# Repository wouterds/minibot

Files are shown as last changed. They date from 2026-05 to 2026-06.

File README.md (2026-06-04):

# minibot

A small invertible 4WD ESP32 robot driven by a PS3 controller over Bluetooth.




## Overview

- **ESP32 (WeMos LOLIN32 Lite)** — WiFi + Bluetooth Classic
- **PS3 DualShock 3 controller** as the wireless remote (BT Classic + HID)
- **4× N20 6 V / 400 RPM** gear motors, paired left/right through a single **DRV8833** dual H-bridge
- **MPU-6050 IMU** for orientation detection — auto-flips drive direction when the bot is upside-down
- **TP4056 USB-C charge + DW01A protection board** — handles charging, overcharge, overdischarge and short-circuit protection
- **1S LiPo 3.7 V / 1000 mAh (603048)**, ~1 hour of cruising
- **3D-printed PETG translucent chassis** — fully enclosed (2.5 mm walls all around), invertible, ~130 × 130 × 18 mm

## System

```mermaid
flowchart LR
    PS3([PS3 Controller]) -->|HID / Bluetooth Classic| ESP[ESP32<br/>LOLIN32 Lite]
    IMU[MPU-6050 IMU] -->|I²C<br/>orientation| ESP
    ESP -->|2 PWM pins / side<br/>3.3 V logic| DRV[DRV8833]
    DRV -->|VM rail| MOT[4× N20 motors<br/>2 paired per side]
    BAT[(1S LiPo<br/>3.7 V / 1000 mAh)] -->|B+ / B-| TP[TP4056<br/>charge + protect]
    TP -->|OUT+ protected VBAT| ESP
    TP -.->|OUT+ to VM| DRV
```

## Wiring

| ESP32 pin | Destination | Purpose |
|---|---|---|
| `3V3` | DRV8833 `SLP`, MPU-6050 `VCC` | Wake the driver, power the IMU |
| `GND` | All `GND` | Common ground |
| `+` pad next to JST | DRV8833 `VM` (from TP4056 `OUT+`) | Motor supply, protected battery (3–4.2 V). Solder to the **pad next to the white JST connector**, not a side-header pin. |
| `GPIO 19` | Status LED | Connection indicator |
| `GPIO 21` | MPU-6050 `SDA` | I²C data (IMU) |
| `GPIO 22` | MPU-6050 `SCL` | I²C clock (IMU) |
| `GPIO 13` | DRV8833 `AIN1` | Left side PWM bit 1 |
| `GPIO 14` | DRV8833 `AIN2` | Left side PWM bit 2 |
| `GPIO 26` | DRV8833 `BIN1` | Right side PWM bit 1 |
| `GPIO 27` | DRV8833 `BIN2` | Right side PWM bit 2 |

Each motor uses **2 PWM-capable GPIOs**: drive one HIGH/PWM and hold the other LOW to spin one direction, swap to reverse. The two motors on each side are wired in parallel to a single driver channel — `AOUT1` / `AOUT2` drive both left motors, `BOUT1` / `BOUT2` both right motors. See [`research.md`](research.md) for the design rationale.

## Power

```mermaid
flowchart LR
    USBC([USB-C 5 V]) -->|Vbus| TP[TP4056<br/>charge IC]
    TP -->|charge| BAT[(1S LiPo<br/>3.0–4.2 V)]
    BAT --> DW[DW01A<br/>protection IC]
    DW -->|OUT+ protected| LDO[LOLIN32<br/>3.3 V LDO]
    DW -->|OUT+ raw| VM[DRV8833 VM]
    LDO -->|3.3 V| LOGIC[ESP32 core<br/>+ DRV8833 SLP, IMU VCC]
    VM -->|3–4 A peak| MOT[4× N20 motors]
```

USB-C plugs into the **TP4056** board: it charges the battery (constant-current → constant-voltage) and the paired **DW01A** protects against overcharge, overdischarge, overcurrent, and short-circuit. The **OUT+ / OUT-** terminals are the protected battery output that feeds both the LOLIN32's 3.3 V LDO and the DRV8833's VM rail. The LOLIN32's onboard TP4054 + JST connector is left unused — battery only ever connects to the TP4056's `B+ / B-`.

## Chassis

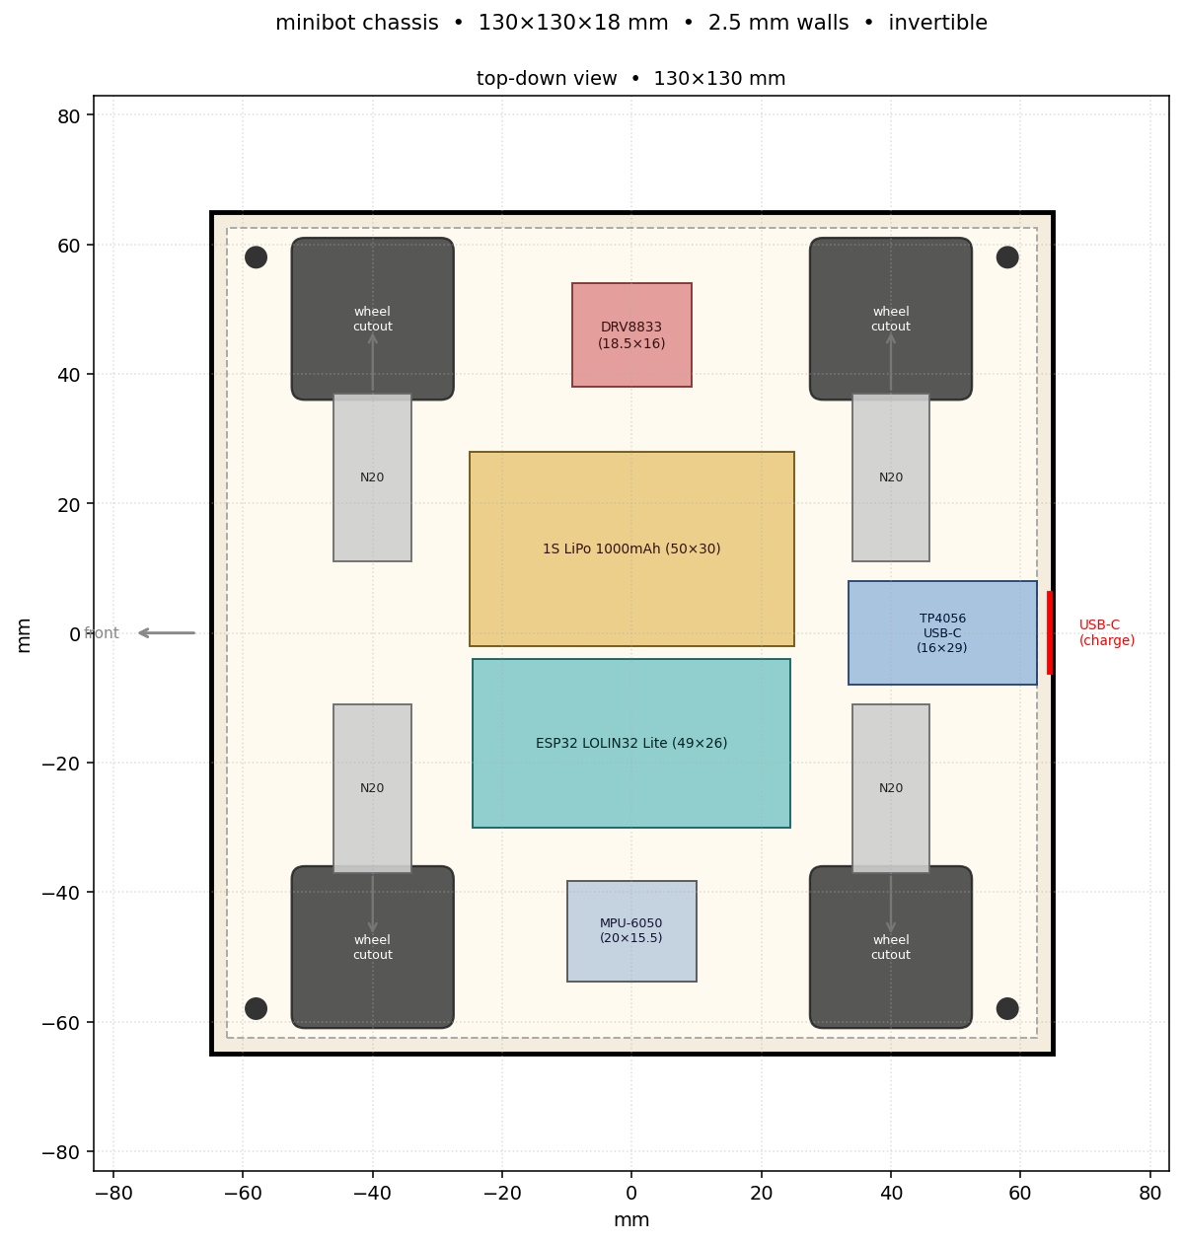
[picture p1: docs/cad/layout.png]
Top-down chassis layout


Two identical tray-shaped plates (3 mm floor + 6 mm half-walls) join open-face-to-open-face into a closed box. Four motors mount in half-cylinder pockets in each plate, shafts pointing outward toward the side walls. Wheels sit on the shafts close to but inside the walls, and protrude only through cutouts in the top and bottom plates. Nothing is exposed laterally.

The parametric source is at [`docs/cad/chassis.scad`](docs/cad/chassis.scad). Render to STL with OpenSCAD:

```sh
openscad --export-format=stl -o plate.stl docs/cad/chassis.scad
```

Print the same shape twice — the chassis is invertible.

### Print settings

| Setting | Value |
|---|---|
| Material | PETG translucent |
| Plate thickness | 3 mm |
| Layer height | 0.2 mm |
| Infill | 25–30 % gyroid |
| Perimeters | 3–4 walls |
| Orientation | Plates flat on the bed |
| Mounting | M2.5 heat-set inserts in the long-edge bosses |

## Parts

Quick summary — see [`docs/parts.md`](docs/parts.md) for the full list with vendors.

| Component | Qty | ~Cost |
|---|---|---:|
| ESP32 LOLIN32 Lite | 1 | €5–8 |
| DRV8833 breakout | 1 | €1.50 |
| N20 6 V 400 RPM motor, 20 mm shaft | 4 | €10 |
| JS2622 wheel (⌀25 × 23 mm) | 4 | €7.20 |
| MPU-6050 IMU module | 1 | €1.50 |
| TP4056 USB-C charge + DW01A protection board | 1 | €1–2 |
| 1S LiPo 1000 mAh (603048) | 1 | €6 |
| PETG translucent (chassis) | ~50 g | €1–2 |
| M2.5 hardware, wire, heat-shrink | — | €5–8 |
| PS3 controller (reuse) | 1 | €0–20 |
| **Total (minimum viable build)** | | **~€33–44** |

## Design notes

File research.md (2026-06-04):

# Research notes

Running log of what we learned while building minibot. Updated as we go.

## Hardware

### ESP32 dev board

- **Chip**: ESP32-D0WDQ6 rev v1.0 — original ESP32, dual-core Xtensa LX6 @ 240 MHz, WiFi + BT/BLE
- **USB-to-serial**: CH340 (`1a86:7523`) → `/dev/cu.usbserial-110`
- **Crystal**: 41.01 MHz reported (a bit off the 40 MHz spec — common quirk on CH340 clones)
- **Base MAC**: `24:6F:28:B1:F8:B4` (WiFi STA)
- **Bluetooth MAC**: `24:6F:28:B1:F8:B6` (= base + 2, per ESP32's MAC derivation rule)
- **Board**: WeMos LOLIN32 Lite (or clone) — confirmed by visible silkscreen + features
- **Footprint**: ~52 × 25 × 5 mm (no headers soldered, direct-wire build)
- **Onboard**:
  - JST PH2.0 connector for 1S LiPo (top edge) — **unused** in current build (battery routes through TP4056 instead)
  - TP4054 LiPo charge IC — **bypassed**; charging handled by external TP4056 + DW01A board
  - 3.3V LDO regulator
  - CH340C USB-serial
  - Micro-USB connector — used for programming only
  - RST button
  - PCB antenna (no external connector)
- **Power pins exposed**:
  - `+` (next to JST) — raw battery voltage (3.0–4.2V), perfect for feeding DRV8833 `VM`
  - `3V` — regulated 3.3V, for DRV8833 `SLP` (sleep/enable) and IMU `VCC`
  - `GND` — common ground
- **Pin labels visible**: `UP` (= GPIO 36 / SENSOR_VP), `UN` (= GPIO 39 / SENSOR_VN), `EN`, plus GPIOs 0, 2, 4, 5, 12–19, 22, 23, 25–27, 32–35

### PS3 controller

- **VID/PID**: `054c:0268` (Sony DualShock 3 / SIXAXIS)
- **Manufacturer string**: `SHANWAN` — it's a clone, not a genuine Sony. Most clones work with standard pairing flow.

### Motors

- **Type**: N20 micro metal gear motors, **6V 400 RPM, 20mm shaft** (4×)
- **Voltage choice**: 6V over 3V because the 3.7V LiPo (4.2V full) overvolts a 3V motor by 23–40%, shortening lifespan and risking thermal failure under stall. Undervolting a 6V motor is harmless — it just runs slower, with more headroom on heat and stall current.
- **Shaft length**: 20mm to match deep-hub wheels (JS2622, measured ⌀25 × 23 mm). Standard ~9mm shafts would slip in deep hubs.
- **RPM choice**: 400 RPM was the practical pick from what's actually in stock — ideal would have been 600 RPM for a snappier "speedy" feel, but 400 RPM is still a usable balance of speed and torque. At 3.7V loaded with the 25mm JS2622 wheels: ~1.0 km/h cruise, ~1.1 km/h peak. Future upgrade path: 2S LiPo (7.4V) would push it to ~1.8 km/h.
- **Visible gear stages identical across all 4** → same gear ratio → same output RPM at same voltage.
- **Current draw**: ~200 mA cruise, 500–700 mA stall per motor. Paired (2× per side) → 1–1.4 A stall per side — within DRV8833's 1.5 A continuous / 2 A peak window.
- **Encoders**: none — open-loop control only (we command, we don't sense).

### Motor driver: DRV8833

Picked over the alternatives for our 4× N20 setup:

| Driver | Price / unit | Continuous | Peak | Notes |
|---|---|---|---|---|
| **DRV8833** ✅ | ~€1.50 | 1.5 A / ch | 2 A (3 A paralleled) | MOSFET, compact (18.5 × 16 mm), no separate VCC needed, fewer GPIOs |
| TB6612FNG | ~€1.50 | 1.2 A / ch | 3 A | MOSFET, clean API (separate PWM pin), but 22 × 22 mm and needs 6 GPIOs instead of 4 |
| L298N | ~€2 | 2 A / ch | — | BJT, ~2 V drop → wastes battery as heat |
| L9110S / MX1508 | ~€1 | 800 mA / ch | — | Marginal for stalled N20s |

Plan: **1× DRV8833 breakout** for the basic 4-motor tank drive — see the [paired-motors topology](#paired-motors-per-side) below: each pair of motors on one side is wired in parallel and treated as one logical motor, so we only need 2 driver channels total.

### DRV8833 control logic

Each motor is driven by **two PWM-capable GPIOs** (no separate PWM-vs-direction pins). Drive one HIGH/PWM and hold the other LOW to spin one direction; swap to reverse:

| `xIN1` | `xIN2` | Result |
|---|---|---|
| `LOW` | `LOW` | Coast (high-impedance, motor freewheels) |
| `PWM` | `LOW` | Forward at PWM duty |
| `LOW` | `PWM` | Reverse at PWM duty |
| `HIGH` | `HIGH` | Brake (short across motor) |

This costs 4 GPIOs total (vs 6 for the TB6612FNG alternative) but requires both pins on each motor channel to be PWM-capable. ESP32 LEDC has 16 channels so that's no constraint.

## Software stack

### Why PlatformIO + Arduino framework

Considered Moddable SDK (TypeScript on ESP) first — beautiful idea but installing the SDK + ESP32 toolchain + ESP-IDF was a multi-GB, multi-hour setup. Dropped TS-as-hard-requirement in favour of:

- **PlatformIO IDE** (VSCode extension) — handles toolchain, library mgr, debugger, monitor, all from one extension
- **Arduino framework** on `espressif32` platform — friendlier than raw ESP-IDF, huge library ecosystem

One click in the PlatformIO status bar = build, upload, monitor. No env vars, no shell config.

### Key library

- `jvpernis/esp32-ps3` (pulled via `lib_deps` git URL) — handles PS3 BT Classic + HID + button/stick event callbacks

## PS3 controller pairing

PS3 pairing is **not** standard Bluetooth pairing. The controller stores **one** host MAC internally and will only connect to that address. There's no discovery, no PIN, no negotiation — the controller hunts for that exact MAC.

To pair:

1. Plug controller into a Mac/Linux host via USB.
2. Write the desired host MAC into the controller's memory via HID feature report `0xF5`.
3. Unplug USB → press PS button → controller auto-connects to that host over Bluetooth.

We do step 2 with `scripts/pair-ps3.py` (uses `hidapi` cython package; runs via `uv` with PEP 723 inline deps).

### Why not just `pip install hid`?

We tried the ctypes-based `hid` package first. On macOS, brew installs `libhidapi.dylib` to `/opt/homebrew/lib` which isn't a default dyld search path, and SIP strips `DYLD_FALLBACK_LIBRARY_PATH` when env-invoking system binaries — so the ctypes loader can never find the library.

The cython-based `hidapi` package builds a self-contained extension during install and bypasses the issue.

## ESP32 GPIO constraints

### Input-only pins (cannot drive outputs / LEDs / motor signals)

- **GPIO 34, 35, 36, 39** — no internal output drivers, no pull-ups/downs. ADC/sensor only.

### Strapping pins (avoid for outputs that need defined boot levels, or be careful)

- **GPIO 0** — boot mode select. Avoid for outputs.
- **GPIO 2** — boot mode. OK if not held HIGH at boot.
- **GPIO 12** — flash voltage select. Must be LOW at boot or chip enters wrong mode → won't boot.
- **GPIO 15** — debug print on boot. Must be HIGH or you lose early boot serial.
- **GPIO 5** — boot mode select. Generally fine as output, just floats high briefly at boot.

### Reserved

- **GPIO 6–11** — wired to internal SPI flash. Touching them = brick.
- **GPIO 1, 3** — UART0 used by USB-serial.

### Currently used

- `19` — status LED (solid when PS3 connected, blinks while waiting)
- `17, 25, 32, 33` — face-button LEDs (will be reallocated when motors arrive)

## Motor control

### Why a driver is mandatory

| | ESP32 GPIO | N20 motor |
|---|---|---|
| Voltage | 3.3 V | 3–6 V |
| Current | 12 mA max | 200 mA – 1 A |
| Direction | one-way | needs polarity swap to reverse |
| Back-EMF | fries logic | spikes voltage on every PWM cycle |

GPIO straight to motor = dead ESP32 in milliseconds.

### H-bridge truth table (DRV8833)

| IN1 | IN2 | Effect |
|---|---|---|
| HIGH | LOW | Forward |
| LOW | HIGH | Reverse |
| LOW | LOW | Coast (free spin) |
| HIGH | HIGH | Brake (short across motor) |

`PWMx` rides on top → speed magnitude.

### Stick → driver mental model

PS3 stick gives signed `-128..+127`. The driver only understands:

- **Unsigned PWM 0–255** (magnitude / how hard)
- **Two direction pins** (which way)

Code splits the signed stick value into `abs()` → PWM and `sign()` → IN1/IN2 levels. The H-bridge handles the polarity flip across the motor terminals so we never need "negative PWM".

### Open-loop vs closed-loop

Our bare N20s have **no encoders**, so we run **open-loop** — we command a direction + speed and trust the motor obeys. For:

- Precise distance ("drive 30 cm")
- Speed regulation under load
- Detecting stall against a wall

…we'd need N20s with **magnetic hall encoders** (~$3–5 extra per motor, quadrature output). Not in scope for v1.

## Power topology

```
USB-C ── TP4056 ── B+/B- ── Battery
              └── OUT+/OUT- ──┬── LOLIN32 + pin (VBAT → onboard 3.3V LDO)
                              └── DRV8833 VM (motor supply)

GND ── common across battery −, TP4056 OUT−, LOLIN32 GND, DRV8833 GND
```

The **TP4056 USB-C board** (with onboard DW01A protection IC) replaces the LOLIN32's built-in charging path:

- **B+ / B-**: battery terminals (TP4056 charges the cell here)
- **OUT+ / OUT-**: protected battery output. Cuts off automatically on overcharge (>4.25 V), overdischarge (<2.4 V), overcurrent or short-circuit.
- USB-C provides 5 V to charge — also passes through to the load while charging, so the bot can be driven from USB.

Why add the TP4056 if the LOLIN32 already has a TP4054 charge IC?

| Feature | LOLIN32 onboard | TP4056 board |
|---|---|---|
| Charge current control | ✅ | ✅ |
| Overcharge protection | ❌ (TP4054 stops at 4.2 V but no protection cutoff) | ✅ DW01A cuts at 4.25 V |
| Overdischarge protection | ❌ | ✅ DW01A cuts at 2.4 V |
| Short-circuit protection | ❌ | ✅ |
| USB connector | micro-USB | USB-C |

For a bot that gets thrown around (and where you really don't want a LiPo to over-discharge), TP4056 is worth the €1.50.

- **VM**: motor power, 3–13.5 V (from TP4056 OUT+, which is battery voltage)
- **VCC**: logic power, 3.3 V (from LOLIN32's onboard LDO, fed from `+` pin)
- **SLP** (sleep/enable on DRV8833): tie to 3.3 V to keep the driver awake (or wire to a GPIO for software sleep)
- **Decoupling**: a 100–470 µF cap across VM/GND helps absorb stall-current dips.

⚠️ Never pull motor current through ESP32's `VIN` or `3V3` pin — onboard LDO maxes out around 800 mA and the input diode is tiny. Motors get their power *directly* from the battery via the driver's `VM`.

⚠️ Don't plug the battery into both the LOLIN32's JST AND the TP4056 B+ at the same time — pick one path. We use TP4056 only.

## Paired motors per side

To save a driver and GPIO budget, **the two motors on each side are wired in parallel** and treated as a single logical motor:

```
Left Front  motor + ─┐
Left Rear   motor + ─┴───── Driver AO1
Left Front  motor − ─┐
Left Rear   motor − ─┴───── Driver AO2
```

(Same for the right side via BO1/BO2.)

Implications:

- **1 driver, not 2** — both sides fit on a single DRV8833 (one channel per side)
- **6 GPIOs instead of 12** for motor control
- **Current doubles per channel** — 2× N20 in parallel pull ~400 mA cruise, ~1.5–2 A at simultaneous stall. Within the DRV8833's 1.5 A continuous / 2 A peak window, but tight enough to want decent decoupling and a battery that can deliver it.
- **Both motors on a side must be matched** (same gear ratio + winding) so they spin at the same RPM under the same drive signal. Our 4× N20s look identical externally + share the same visible gear stages, so this should hold.
- **Wire polarity matters** — if a paired motor spins the "wrong way" relative to its partner, just flip its leads at the driver output. Don't try to fix it in software.

## Wiring plan (1× DRV8833, 4 motors paired, tank drive)

| Side | IN1 (PWM) | IN2 (PWM) | Driver / output | Motors |
|---|---|---|---|---|
| Left  | GPIO 13 | GPIO 14 | A channel (AOUT1 + AOUT2) | Left Front + Left Rear in parallel |
| Right | GPIO 26 | GPIO 27 | B channel (BOUT1 + BOUT2) | Right Front + Right Rear in parallel |

`SLP` → ESP32 `3V3`. `VM` → TP4056 `OUT+` (battery, 3–4.2 V). All `GND` rails common (battery −, ESP32 GND, driver GND). No separate VCC pin needed — DRV8833 self-powers its logic from VM.

Final pin budget: 4 GPIO for motors + 1 status LED (GPIO 19) + 2 GPIO for I²C (21/22) = 7 used. Plenty of headroom for future sensors (ultrasonic, encoders, NeoPixels, etc.).

## IMU for orientation detection

A **MPU-6050 (MPU6050)** module sits on the I²C bus (SDA → GPIO 21, SCL → GPIO 22) and reports the gravity vector via its accelerometer. Because the chassis is invertible, drive direction needs to flip automatically when the bot is on its other face:

- Right-side-up → accelerometer Z axis points one way → forward = +X
- Upside-down → Z flips sign → "forward" stick should drive the wheels the other way
- Left/right also swap when flipped

The integration plan when the motors arrive is:

```cpp
bool flipped = imu::isUpsideDown();         // sign of accel Z
if (flipped) {
  forward = !forward;
  std::swap(leftSpeed, rightSpeed);
}
```

with ~200 ms hysteresis so a quick yeet during driving doesn't trigger a direction flip mid-stride. The MPU6050 also leaves room for future features (tilt-aware drive, crash detection, optional self-balance mode).

## Chassis

### Concept: fully enclosed, wheels inside the perimeter, invertible

Two identical "tray" plates that join open-face-to-open-face into a closed box. Each plate has a 3 mm flat floor and 6 mm half-walls around its perimeter; when stacked together they form an 18 mm tall enclosure with continuous 12 mm cavity inside. **Side panels (3 mm) on all four sides** — nothing is exposed laterally.

```
                                ┌─────────────────────┐
              3mm TOP PLATE  ►  │═════════════════════│  ◀ top plate has wheel
                  6mm wall   ►  │                     │    cutouts for protrusion
                                │  ◯ motor      ◯     │
                                │   wheel  ESP32      │   12mm motor cavity
                                │           battery   │
                                │  ◯ motor      ◯     │
                  6mm wall   ►  │                     │  ◀ bottom plate also has
              3mm BOT PLATE  ►  │═════════════════════│    cutouts (chassis is
                                └─────────────────────┘    invertible)
```

The motors mount **shaft-outward** — bodies sit toward the chassis centre, shafts and wheels point outward to the side walls. Wheels are tucked **just inside the wall** (a few millimetres of clearance), and they poke out **only through cutouts in the top and bottom plates** — nothing protrudes laterally. Wheels protrude **~7.5 mm above and below** the chassis floor/ceiling, so the bot drives the same right-side-up or upside-down (invertible).

### Dimensions

| | |
|---|---|
| Plate length | **130 mm** (front-to-back) |
| Plate width | **130 mm** (side-to-side, square footprint) |
| Plate thickness | 3 mm |
| Wall thickness | 2.5 mm |
| Wall height per plate | 6 mm (×2 = 12 mm cavity) |
| Total chassis height | **18 mm** (3 + 6 + 6 + 3) |
| Motor track (centres) | **48 mm** |
| Motor axle pitch (wheelbase) | 80 mm |
| Wheel positions | shaft-outward from motors; wheel centres at ±47.5 mm in Y |
| Wheel cutout per plate | ~30 × 22 mm rounded slot (×4) |
| Mounting | M2.5 heat-set inserts in corner bosses |
| Side access | micro-USB slot in the front wall |

### Material: PETG translucent

| Property | Why it matters here |
|---|---|
| Impact resistant | Survives drops, motor vibration, table yeets |
| Layer adhesion | No delamination under chassis stress |
| ~75 °C glass transition | Fine for indoor robot use (PLA would soften in a hot car / direct sun) |
| Easy to print | No warp, no ABS-style fumes |
| **Translucent** | Internal LEDs glow through the chassis → the whole bot becomes a status indicator 💡 |

### Print parameters

| Setting | Value |
|---|---|
| Plate thickness | **3 mm** (4 mm if you want extra stiffness) |
| Layer height | 0.2 mm body, 0.1 mm for crisp pocket walls |
| Infill | 25–30 % gyroid |
| Perimeters | 3–4 walls |
| Orientation | Plates printed **flat** on the bed (strongest along load axes) |
| Tolerance for press fits | +0.2–0.3 mm on pocket diameters (PETG extrudate is slightly wider than nozzle) |
| Mounting | M2.5 heat-set inserts in printed bosses |

### Build constraints

Driving everything from "no component sticks above the chassis":

- **Boards have no headers** — wires soldered directly to ESP32 pads (loses easy disassembly, gains height)
- **LOLIN32 Lite footprint** (52 × 25 × 5 mm) fits comfortably in the 12 mm cavity
- **DRV8833** (~18.5 × 16 × 4 mm) fits flat with room to spare
- **LiPo battery** (height < 12 mm, confirmed by inspection) → fits anywhere in the cavity
- **Cable channels** — 1.5 mm grooves in plate inner faces for routing wires

### Side-access requirements (because invertible + enclosed)

The robot has no fixed top/bottom AND no exposed sides, so external interfaces all live in cutouts through the side walls:

- [x] Micro-USB cutout in the front wall (for programming + battery charging)
- [ ] Power switch slot (optional — alternatively, plug/unplug JST battery)
- [ ] Optional: vent slots if DRV8833 runs hot under heavy stall

### Design checklist (current chassis.scad reflects all of this)

- [x] Two identical "tray" plates with 3 mm floor + 6 mm half-walls = invertible
- [x] 4× half-cylinder motor pockets in each plate (motors lie on their side, shaft outward)
- [x] 4× wheel cutouts through each plate (top + bottom) so the wheel can protrude
- [x] Electronics recesses: ESP32 (49 × 26 mm), DRV8833 (18.5 × 16 mm), battery (~50 × 30 × 6 mm, 603048), MPU-6050 (20 × 15.5 mm), TP4056 (29 × 16 mm)
- [x] Mounting holes through the corner walls for M2.5 heat-set inserts
- [x] Front-wall USB slot

### Translucency affordance 💡

Because the chassis is translucent PETG, **any LED placed inside the chassis becomes a chassis-wide glow**:

- The existing `STATUS_LED` (GPIO 19) becomes a full-bot status indicator
- Optional: add a short WS2812B / NeoPixel strip (5 LEDs ≈ €1) along the centerline → ambient lighting, direction indicators, low-battery pulse, etc. ESP32 drives NeoPixels off any GPIO using the `Adafruit_NeoPixel` or `FastLED` library; one data pin + 5V + GND.
- Wall thickness affects glow: 2 mm walls = bright/visible LED, 4 mm walls = diffused even glow. Mix for accent vs. ambient.

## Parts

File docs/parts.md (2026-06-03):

# Parts

Everything needed to build a minibot from scratch. Prices are rough Euro estimates from AliExpress in 2026 — Amazon / Adafruit / Sparkfun are 2–3× higher but ship faster.

## Electronics

| Qty | Component | Notes | Unit price | Subtotal |
|---|---|---|---:|---:|
| 1 | **WeMos LOLIN32 Lite** (ESP32 + CH340 + JST + TP4054) | The brain. Search "LOLIN32 Lite" on AliExpress. | €5–8 | €5–8 |
| 1 | **DRV8833 dual motor driver breakout** | Pololu-style carrier, ~18.5 × 16 mm. Drives 2 motors at 1.5 A continuous / 2 A peak per channel. Recommend buying spares. | €1.50 | €1.50 |
| 4 | **N20 6V 400 RPM micro metal gearmotor**, 20 mm shaft, D-cut | Get them all from one listing so they're matched. Search "N20 6V 400rpm 20mm shaft". | €2.50 | €10 |
| 4 | **JS2622 wheel** (rubber tire), D-shaft hub | Measured ⌀25 mm × 23 mm wide. Rides on the motor's long shaft. | €1.80 | €7.20 |
| 1 | **MPU-6050 IMU module** | 6-axis accel + gyro on I²C. Used to detect upside-down and auto-flip drive direction. Spare buying recommended — 5 for ~€1.50 each. | €1.50 | €1.50 |
| 1 | **TP4056 USB-C charge + DW01A protection board** (the "18650 Type-C" board) | Charges the battery via USB-C and protects against overcharge / overdischarge / overcurrent / short-circuit. OUT+ / OUT- feed the load (replaces the LOLIN32's onboard charger path). | €1–2 | €1.50 |
| 1 | **1S LiPo 3.7 V 1000 mAh** pouch (603048, ~50 × 30 × 6 mm measured) | 6 mm thick fits the 12 mm cavity easily. Wires solder directly to TP4056 B+ / B-. | €6 | €6 |
| 1 | **PS3 controller** (DualShock 3, original or SHANWAN clone) | Reuse one you already have. SHANWAN clones are €15–25 new. | €0–20 | €0 |
| | | | **electronics** | **€33–57** |

## Mechanical / fasteners

| Qty | Component | Notes | Unit price | Subtotal |
|---|---|---|---:|---:|
| 1 set | **PETG translucent filament**, ~50 g for both plates | Any reputable brand (Polymaker / eSun / Prusament). 1 kg spool ≈ €20; chassis uses €1–2 worth. | — | €1–2 |
| 4 | **M2.5 × 10 mm machine screws** (chassis assembly) | | €0.10 | €0.40 |
| 4 | **M2.5 heat-set inserts** (M2.5 × 4 mm OD, brass) | Pressed into the printed bosses with a soldering iron. | €0.20 | €0.80 |
| 1 | **Misc**: silicone wire 24–28 AWG (~2 m), heat shrink, solder | | — | €3–5 |
| | | | **mechanical** | **€5–8** |

## Optional add-ons (for v2+)

| Qty | Component | Notes | Unit price |
|---|---|---|---:|
| 1 | **WS2812B / NeoPixel strip** (5–10 LEDs) | Glow effects through the translucent chassis. ESP32 drives directly. | €1–3 |
| 1 | **HC-SR04 ultrasonic distance sensor** | Obstacle detection. ~€1 on AliExpress. | €1 |
| 1 | **N20 encoder add-on** (magnetic hall, ×2 or ×4) | Closed-loop speed control / odometry. ~€3 per motor. | €3 |

## Total estimate

| Tier | What you get | Estimated cost |
|---|---|---:|
| **Minimum viable** (reuse PS3 controller, 1 driver only) | A working invertible 4WD bot | **~€33–44** |
| **Comfortable** (spare driver, new controller, extras) | Same bot + spares + buffer | **~€55–80** |
| **Loaded** (all add-ons) | Bot with NeoPixels + ultrasonic + encoders | **~€80–110** |

## Sources

| Vendor | Strength | Weakness |
|---|---|---|
| **AliExpress** | Cheapest by ~3×, all parts available | 2–4 week shipping, quality varies |
| **Amazon** | Fast (1–2 days), well-known brands | 2–3× the price |
| **Adafruit / Sparkfun** | US warehoused, high-quality breakouts, great docs | Most expensive option |
| **TinyTronics / Reichelt / Mouser** (EU) | Fast EU shipping, professional parts | More expensive than Ali |
| **Pimoroni** (UK) | Fast EU/UK shipping, curated selection | Limited motor selection |

## Already on hand (don't re-buy)

- USB cable for programming (any micro-USB cable, ≥30 cm)
- Soldering iron + flux + solder
- 3D printer with PETG capability
- Computer running VSCode + PlatformIO
- Phone with a USB-C or Lightning charger (for the LiPo charger circuit on the LOLIN32)

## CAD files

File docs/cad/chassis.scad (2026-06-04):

// minibot chassis — parametric, invertible, fully enclosed
//
// Two identical tray plates that join open-face to open-face into a
// closed box. Each plate has a 3 mm floor + 6 mm half-walls; together
// they form an 18 mm tall enclosure with a 12 mm internal cavity.
//
// Motors mount with shafts pointing OUTWARD toward the side walls.
// Wheels are mounted on the shafts close to (but inside) the side
// walls; they poke through cutouts in the top and bottom plates only,
// so nothing protrudes laterally.
//
//   openscad --export-format=stl -o plate.stl docs/cad/chassis.scad
//
// The chassis is invertible — print this same shape twice.

// ─── parameters ──────────────────────────────────────────────────────

// Outer footprint
plate_length = 130;     // mm — front-to-back (corner screws clear of the wheels)
plate_width  = 130;     // mm — side-to-side (square footprint)
plate_thick  = 3;       // mm — flat floor thickness

// Walls — 6 mm tall on each plate, meeting in the cavity centreline
wall_thick       = 2.5;
wall_half_height = 6;

// N20 motor body (measured: 12 mm wide × 10 mm tall when laid on its side)
motor_width      = 12;          // X dimension (lateral when laid flat)
motor_height     = 10;          // Z dimension (perpendicular to plate)
motor_diameter   = motor_width; // legacy alias used by half-cylinder pocket math below
motor_length     = 26;          // body only, excluding shaft (measured)
motor_axle_pitch = 80;  // mm — wheels pulled in a little, clear of the corner screws
motor_track      = 48;  // mm — tyres sit 1 mm from the side walls (also clears TP4056)

// Pocket geometry (half-cylinder cut into the plate)
pocket_depth     = motor_diameter / 2;
pocket_clearance = 0.3;

// Wheels (measured: 25 mm outer diameter incl. rubber tire × 23 mm wide).
// Mounted on the motor's long shaft, which runs into the wheel hub.
wheel_diameter  = 25;
wheel_width     = 23;
wheel_clearance = 2.0;

// Electronics
esp_length = 49;
esp_width  = 26;
esp_pocket_depth = 2;

driver_length = 18.5;   // DRV8833 carrier (measured)
driver_width  = 16;
driver_pocket_depth = 2;

battery_length = 50;   // 603048 LiPo: 48 mm nominal, ~50 mm measured incl. sealed lip
battery_width  = 30;
battery_pocket_depth = 2;

// MPU-6050 (MPU6050) IMU breakout
imu_length = 20;
imu_width  = 15.5;
imu_pocket_depth = 2;

// TP4056 USB-C charging + protection board (PCB 26.5mm, +2.5mm for the USB-C connector overhang)
tp4056_length = 29;
tp4056_width  = 16;
tp4056_pocket_depth = 2;

// Corner mount holes (M2.5 heat-set inserts).
mount_hole_d     = 2.7;
mount_hole_inset = 7;

// Micro-USB slot in the front wall
usb_slot_width  = 12;
usb_slot_height = 6;

// Render resolution
$fa = 4;
$fs = 0.5;


// ─── derived geometry ────────────────────────────────────────────────

motor_pocket_d = motor_diameter + pocket_clearance;

// Motor body Y-position (motor centre). Body extends ±motor_length/2 in Y.
motor_center_y = motor_track / 2;

// Wheel Y-position: the wheel is pushed onto the long shaft until the
// shaft tip is flush with the wheel's OUTER face. The shaft engagement
// equals the wheel width (25 mm), which places the wheel's INNER face
// right at the motor's gearbox face. So:
//   wheel_centre = gearbox_face + wheel_width/2
//                = (motor_center_y + motor_length/2) + wheel_width/2
wheel_center_y = motor_center_y + motor_length / 2 + wheel_width / 2;

motor_positions = [
  [-motor_axle_pitch / 2,  motor_center_y],   // front-left
  [-motor_axle_pitch / 2, -motor_center_y],   // front-right
  [ motor_axle_pitch / 2,  motor_center_y],   // rear-left
  [ motor_axle_pitch / 2, -motor_center_y],   // rear-right
];

wheel_positions = [
  [-motor_axle_pitch / 2,  wheel_center_y],
  [-motor_axle_pitch / 2, -wheel_center_y],
  [ motor_axle_pitch / 2,  wheel_center_y],
  [ motor_axle_pitch / 2, -wheel_center_y],
];

// Wheel cross-section through the plate is widest at the plate's inner
// surface (closest to the wheel centre at z = cavity centre). For a
// 25 mm wheel centred at z = 9 mm in an 18 mm chassis, the chord at
// z = 3 mm (plate top) is 2·sqrt(12.5² − 6²) ≈ 22 mm; round up with
// clearance for the rubber to flex.
wheel_cutout_x = 24;
wheel_cutout_y = wheel_width + 1;  // keeps the slot just clear of the side wall


// ─── modules ─────────────────────────────────────────────────────────

module motor_pocket(pos)
{
  // Half-cylinder along Y axis cut into the floor
  translate([pos[0], pos[1], plate_thick - pocket_depth])
    rotate([90, 0, 0])
      cylinder(d=motor_pocket_d, h=motor_length, center=true);
}

module wheel_cutout(pos)
{
  // Rounded-rectangle slot through the plate
  translate([pos[0], pos[1], -1])
    linear_extrude(plate_thick + 2)
      offset(r=2)
        square([wheel_cutout_x - 4, wheel_cutout_y - 4], center=true);
}

module rect_pocket(w, l, depth, x=0, y=0)
{
  translate([x, y, plate_thick - depth])
    linear_extrude(depth + 1)
      square([l, w], center=true);
}

module mount_holes()
{
  for (sx = [-1, 1]) for (sy = [-1, 1])
    translate([
      sx * (plate_length / 2 - mount_hole_inset),
      sy * (plate_width  / 2 - mount_hole_inset),
      -1
    ])
      cylinder(d=mount_hole_d, h=plate_thick + wall_half_height + 2);
}

module usb_slot()
{
  // Slot through the back wall (+X), centred. The ESP32's micro-USB
  // connector reaches it through a short internal cable / extension.
  translate([
    plate_length / 2 - wall_thick - 0.1,
    -usb_slot_width / 2,
    plate_thick + (wall_half_height - usb_slot_height) / 2
  ])
    cube([wall_thick + 0.2, usb_slot_width, usb_slot_height]);
}

module plate()
{
  difference() {
    union() {
      // Floor
      translate([-plate_length / 2, -plate_width / 2, 0])
        cube([plate_length, plate_width, plate_thick]);
      // Walls
      difference() {
        translate([-plate_length / 2, -plate_width / 2, 0])
          cube([plate_length, plate_width, plate_thick + wall_half_height]);
        translate([
          -plate_length / 2 + wall_thick,
          -plate_width  / 2 + wall_thick,
          plate_thick
        ])
          cube([
            plate_length - 2 * wall_thick,
            plate_width  - 2 * wall_thick,
            wall_half_height + 1
          ]);
      }
    }

    // Motor half-pockets in the floor
    for (p = motor_positions) motor_pocket(p);

    // Wheel cutouts through the plate
    for (p = wheel_positions) wheel_cutout(p);

    // Electronics recesses. Battery + ESP32 stack flat in the centre (both
    // ~50 mm long in X, only ±25 mm wide so they clear the corner motors).
    // DRV8833 + MPU-6050 sit on the two sides; TP4056 fills the back centre
    // with its USB-C reaching the back-wall slot.
    rect_pocket(battery_width, battery_length, battery_pocket_depth, x=0,  y=+13);  // 50×30
    rect_pocket(esp_width,     esp_length,     esp_pocket_depth,     x=0,  y=-17);  // 49×26
    rect_pocket(driver_width,  driver_length,  driver_pocket_depth,  x=0,  y=+46);  // 18.5×16
    rect_pocket(imu_width,     imu_length,     imu_pocket_depth,     x=0,  y=-46);  // 20×15.5
    rect_pocket(tp4056_width,  tp4056_length,  tp4056_pocket_depth,  x=48, y=0);    // 29×16

    // USB slot through the front wall
    usb_slot();

    // Corner mount holes
    mount_holes();
  }
}


// ─── render ──────────────────────────────────────────────────────────

plate();

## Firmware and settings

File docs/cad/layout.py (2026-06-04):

#!/usr/bin/env -S uv run --quiet --script
# /// script
# requires-python = ">=3.10"
# dependencies = ["matplotlib>=3.9"]
# ///
"""Top-down + side view chassis layout — mirrors chassis.scad geometry."""

from pathlib import Path

import matplotlib.patches as patches
import matplotlib.pyplot as plt

OUT = Path(__file__).resolve().parent

# ─── parameters (kept in sync with chassis.scad) ────────────────────
plate_length = 130
plate_width = 130
plate_thick = 3       # floor thickness (Z)
wall_thick = 2.5      # perimeter wall thickness (X/Y)
wall_half_height = 6  # half of the cavity height (so cavity = 12 mm)

motor_width = 12       # X dimension when laid flat
motor_height = 10      # Z dimension (perpendicular to plate)
motor_diameter = motor_width
motor_length = 26      # body only, excluding shaft
motor_axle_pitch = 80
motor_track = 48

wheel_diameter = 25      # measured outer diameter incl. rubber tire
wheel_width = 23
wheel_clearance = 2.0

motor_center_y = motor_track / 2
wheel_center_y = motor_center_y + motor_length / 2 + wheel_width / 2

esp_length, esp_width = 49, 26
driver_length, driver_width = 18.5, 16
battery_length, battery_width = 50, 30
imu_length, imu_width = 20, 15.5
tp4056_length, tp4056_width = 29, 16

esp_thick = 4         # PCB + components (Z direction)
driver_thick = 4
battery_thick = 6
imu_thick = 3
tp4056_thick = 3

chassis_height = 2 * plate_thick + 2 * wall_half_height  # = 18 mm
cavity_z_center = chassis_height / 2

motor_positions = [
    (-motor_axle_pitch / 2,  motor_center_y),
    (-motor_axle_pitch / 2, -motor_center_y),
    ( motor_axle_pitch / 2,  motor_center_y),
    ( motor_axle_pitch / 2, -motor_center_y),
]

wheel_positions = [
    (-motor_axle_pitch / 2,  wheel_center_y),
    (-motor_axle_pitch / 2, -wheel_center_y),
    ( motor_axle_pitch / 2,  wheel_center_y),
    ( motor_axle_pitch / 2, -wheel_center_y),
]

# Component centre positions. Battery + ESP32 stack flat in the centre
# (each ~50 mm long in X, only ±25 mm wide so they clear the corner
# motors). DRV8833 + MPU-6050 on the two sides; TP4056 fills the back
# centre with its USB-C reaching the back-wall slot.
bat_x, bat_y = 0, +13
esp_x, esp_y = 0, -17
drv_x, drv_y = 0, +46
imu_pos_x, imu_pos_y = 0, -46
tp_x, tp_y = 48, 0


def draw_top(ax) -> None:
    # Outer chassis outline
    ax.add_patch(patches.Rectangle(
        (-plate_length / 2, -plate_width / 2),
        plate_length, plate_width,
        linewidth=2.5, edgecolor="black", facecolor="#f4ecdc",
    ))
    ax.add_patch(patches.Rectangle(
        (-plate_length / 2 + wall_thick, -plate_width / 2 + wall_thick),
        plate_length - 2 * wall_thick, plate_width - 2 * wall_thick,
        linewidth=1, edgecolor="#aaa", facecolor="#fffaf0", linestyle="--",
    ))

    cutout_x = 24
    cutout_y = wheel_width + 1
    for x, y in wheel_positions:
        ax.add_patch(patches.FancyBboxPatch(
            (x - cutout_x / 2, y - cutout_y / 2),
            cutout_x, cutout_y,
            boxstyle="round,pad=0.5,rounding_size=2",
            linewidth=1.2, edgecolor="#222", facecolor="#3a3a3a", alpha=0.85,
        ))
        ax.text(x, y, "wheel\ncutout", ha="center", va="center",
                fontsize=6.5, color="white")

    for x, y in motor_positions:
        ax.add_patch(patches.Rectangle(
            (x - motor_diameter / 2, y - motor_length / 2),
            motor_diameter, motor_length,
            linewidth=1, edgecolor="#666", facecolor="#cfcfcf", alpha=0.9,
        ))
        ax.text(x, y, "N20", ha="center", va="center", fontsize=6.5, color="#222")
        sign = 1 if y > 0 else -1
        ax.annotate(
            "", xy=(x, y + sign * (motor_length / 2 + 10)),
            xytext=(x, y + sign * motor_length / 2),
            arrowprops=dict(arrowstyle="->", color="#777", lw=1.2),
        )

    # Battery — flat (long axis X), centre
    ax.add_patch(patches.Rectangle(
        (bat_x - battery_length / 2, bat_y - battery_width / 2),
        battery_length, battery_width,
        linewidth=1, edgecolor="#640", facecolor="#e8c878", alpha=0.85,
    ))
    ax.text(bat_x, bat_y, f"1S LiPo 1000mAh ({battery_length}×{battery_width})",
            ha="center", va="center", fontsize=7, color="#311")

    # DRV8833 — on the +Y side, centred in X
    ax.add_patch(patches.Rectangle(
        (drv_x - driver_length / 2, drv_y - driver_width / 2),
        driver_length, driver_width,
        linewidth=1, edgecolor="#722", facecolor="#e08e8e", alpha=0.85,
    ))
    ax.text(drv_x, drv_y, f"DRV8833\n({driver_length}×{driver_width})",
            ha="center", va="center", fontsize=7, color="#311")

    # MPU-6050 — on the -Y side, centred in X
    ax.add_patch(patches.Rectangle(
        (imu_pos_x - imu_length / 2, imu_pos_y - imu_width / 2),
        imu_length, imu_width,
        linewidth=1, edgecolor="#444", facecolor="#bcd", alpha=0.85,
    ))
    ax.text(imu_pos_x, imu_pos_y, f"MPU-6050\n({imu_length}×{imu_width})",
            ha="center", va="center", fontsize=6.5, color="#113")

    # ESP32 — flat (long axis X), below the battery
    ax.add_patch(patches.Rectangle(
        (esp_x - esp_length / 2, esp_y - esp_width / 2),
        esp_length, esp_width,
        linewidth=1, edgecolor="#055", facecolor="#7ec8c8", alpha=0.85,
    ))
    ax.text(esp_x, esp_y, f"ESP32 LOLIN32 Lite ({esp_length}×{esp_width})",
            ha="center", va="center", fontsize=7, color="#022")

    # TP4056
    ax.add_patch(patches.Rectangle(
        (tp_x - tp4056_length / 2, tp_y - tp4056_width / 2),
        tp4056_length, tp4056_width,
        linewidth=1, edgecolor="#136", facecolor="#9bd", alpha=0.85,
    ))
    ax.text(tp_x, tp_y, f"TP4056\nUSB-C\n({tp4056_width}×{tp4056_length})",
            ha="center", va="center", fontsize=6.5, color="#013")

    # USB-C slot
    ax.plot([plate_length / 2 - 0.5, plate_length / 2 - 0.5],
            [-6, 6], color="red", lw=3)
    ax.text(plate_length / 2 + 4, 0, "USB-C\n(charge)",
            ha="left", va="center", fontsize=7, color="red")

    # Corner mount holes
    for sx in (-1, 1):
        for sy in (-1, 1):
            ax.add_patch(patches.Circle(
                (sx * (plate_length / 2 - 7), sy * (plate_width / 2 - 7)),
                1.6, color="#333", zorder=10,
            ))

    # Driving direction arrow
    ax.annotate(
        "", xy=(-plate_length / 2 - 12, 0),
        xytext=(-plate_length / 2 - 2, 0),
        arrowprops=dict(arrowstyle="->", color="#888", lw=1.5),
    )
    ax.text(-plate_length / 2 - 14, 0, "front",
            fontsize=8, color="#888", va="center", ha="right")

    ax.set_xlim(-plate_length / 2 - 18, plate_length / 2 + 18)
    ax.set_ylim(-plate_width / 2 - 18, plate_width / 2 + 18)
    ax.set_aspect("equal")
    ax.set_title(
        f"top-down view  •  {plate_length}×{plate_width} mm",
        fontsize=10,
    )
    ax.set_xlabel("mm")
    ax.set_ylabel("mm")
    ax.grid(True, linestyle=":", alpha=0.4)


def draw_side(ax) -> None:
    """X–Z view, looking at the bot from the +Y side."""

    # Chassis envelope (overall outline)
    ax.add_patch(patches.Rectangle(
        (-plate_length / 2, 0),
        plate_length, chassis_height,
        linewidth=2, edgecolor="black", facecolor="#f4ecdc",
    ))
    # Bottom plate floor band
    ax.add_patch(patches.Rectangle(
        (-plate_length / 2, 0),
        plate_length, plate_thick,
        linewidth=0, facecolor="#e3d4b0",
    ))
    # Top plate floor band
    ax.add_patch(patches.Rectangle(
        (-plate_length / 2, chassis_height - plate_thick),
        plate_length, plate_thick,
        linewidth=0, facecolor="#e3d4b0",
    ))

    # Wheel cutout slots in the plates at each wheel X
    cutout_x_side = 28
    for x, _ in wheel_positions[:2]:  # only x positions matter (each appears twice)
        for z_band in (0, chassis_height - plate_thick):
            ax.add_patch(patches.Rectangle(
                (x - cutout_x_side / 2, z_band),
                cutout_x_side, plate_thick,
                linewidth=0, facecolor="white",
            ))

    # Wheels: full circles centred at cavity centre, protruding above/below
    for x in (-motor_axle_pitch / 2, motor_axle_pitch / 2):
        ax.add_patch(patches.Circle(
            (x, cavity_z_center),
            wheel_diameter / 2,
            linewidth=1.5, edgecolor="#222", facecolor="#3a3a3a", alpha=0.9,
        ))
        ax.text(x, cavity_z_center + wheel_diameter / 2 + 1.5,
                f"⌀{wheel_diameter}",
                ha="center", va="bottom", fontsize=6.5, color="#444")

    # Motors at each X (front + rear), shown as 12×10 rectangles in X–Z
    for x in (-motor_axle_pitch / 2, motor_axle_pitch / 2):
        ax.add_patch(patches.Rectangle(
            (x - motor_width / 2, cavity_z_center - motor_height / 2),
            motor_width, motor_height,
            linewidth=1, edgecolor="#666", facecolor="#cfcfcf", alpha=0.75,
        ))

    # Electronics sitting on the bottom plate floor (z = plate_thick → up)
    components = [
        (drv_x, driver_length, driver_thick, "#e08e8e", "#722", "DRV"),
        (imu_pos_x - driver_length / 2 - 5, imu_length, imu_thick, "#bcd", "#444", "IMU"),
        (bat_x, battery_length, battery_thick, "#e8c878", "#640", "battery"),
        (esp_x, esp_length, esp_thick, "#7ec8c8", "#055", "ESP32"),
        (tp_x, tp4056_length, tp4056_thick, "#9bd", "#136", "TP4056"),
    ]
    for cx, cwidth_x, cthick, fcol, ecol, label in components:
        ax.add_patch(patches.Rectangle(
            (cx - cwidth_x / 2, plate_thick + 0.1),
            cwidth_x, cthick,
            linewidth=0.8, edgecolor=ecol, facecolor=fcol, alpha=0.85,
        ))
        ax.text(cx, plate_thick + cthick / 2 + 0.1, label,
                ha="center", va="center", fontsize=6.5, color=ecol)

    # USB-C slot in the back wall
    ax.add_patch(patches.Rectangle(
        (plate_length / 2 - wall_thick, plate_thick + 1),
        wall_thick, 6,
        linewidth=0, facecolor="red", alpha=0.7,
    ))
    ax.text(plate_length / 2 + 1, plate_thick + 4, "USB-C", ha="left",
            va="center", fontsize=7, color="red")

    # Annotate chassis height and wheel protrusion
    wheel_top = cavity_z_center + wheel_diameter / 2
    wheel_bot = cavity_z_center - wheel_diameter / 2
    ax.text(-plate_length / 2 - 4, chassis_height / 2,
            f"{chassis_height:g} mm\nchassis",
            ha="right", va="center", fontsize=7, color="#555")
    ax.text(plate_length / 2 + 18, wheel_top - 0.5,
            f"+{wheel_top - chassis_height:g} mm",
            ha="left", va="center", fontsize=6.5, color="#555")
    ax.text(plate_length / 2 + 18, wheel_bot + 0.5,
            f"−{-wheel_bot:g} mm",
            ha="left", va="center", fontsize=6.5, color="#555")

    ax.set_xlim(-plate_length / 2 - 18, plate_length / 2 + 30)
    ax.set_ylim(wheel_bot - 6, wheel_top + 6)
    ax.set_aspect("equal")
    ax.set_title(
        f"side view  •  chassis {chassis_height:g} mm tall  •  wheel ⌀ {wheel_diameter} mm",
        fontsize=10,
    )
    ax.set_xlabel("mm  (length)")
    ax.set_ylabel("mm  (height)")
    ax.grid(True, linestyle=":", alpha=0.4)


def render() -> None:
    fig, ax_top = plt.subplots(figsize=(11, 9), dpi=140)
    fig.suptitle(
        f"minibot chassis  •  {plate_length}×{plate_width}×{chassis_height:g} mm  •  "
        f"{wall_thick:g} mm walls  •  invertible",
        fontsize=11, y=0.995,
    )
    draw_top(ax_top)
    fig.tight_layout()
    fig.savefig(OUT / "layout.png", bbox_inches="tight")
    print(f"wrote: {OUT / 'layout.png'}")


if __name__ == "__main__":
    render()

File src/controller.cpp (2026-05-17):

#include "controller.h"
#include "buzzer.h"
#include "config.h"
#include "rgb.h"
#include "status_led.h"
#include <Arduino.h>
#include <Ps3Controller.h>

namespace controller
{

static void onConnect()
{
  Serial.println("PS3 connected");
  status_led::setConnected(true);
}

static void onDisconnect()
{
  Serial.println("PS3 disconnected");
  status_led::setConnected(false);
  rgb::off();
  buzzer::off();
}

static void onNotify()
{
  // Preset selection — sets the RGB output to that colour.
  if (Ps3.event.button_down.triangle)
  {
    rgb::activate(rgb::GREEN);
    Serial.println("△ green");
  }
  if (Ps3.event.button_down.circle)
  {
    rgb::activate(rgb::RED);
    Serial.println("○ red");
  }
  if (Ps3.event.button_down.square)
  {
    rgb::activate(rgb::PINK);
    Serial.println("□ pink");
  }
  if (Ps3.event.button_down.cross)
  {
    rgb::activate(rgb::BLUE);
    Serial.println("✕ blue");
  }

  // Buzzer while any shoulder button is held.
  const bool shoulder = Ps3.data.button.l1 || Ps3.data.button.l2 || Ps3.data.button.r1 ||
                        Ps3.data.button.r2;
  if (shoulder)
  {
    buzzer::on();
  }
  else
  {
    buzzer::off();
  }
}

void begin()
{
  Ps3.attach(onNotify);
  Ps3.attachOnConnect(onConnect);
  Ps3.attachOnDisconnect(onDisconnect);
  Ps3.begin(config::HOST_MAC);

  Serial.printf("Waiting for PS3 controller on %s ...\n", config::HOST_MAC);
}

void update()
{
  if (!Ps3.isConnected())
  {
    status_led::blinkWhileWaiting();
    delay(50);
    return;
  }

  // Right stick Y → global brightness scale (up = brighter)
  const int8_t ry = Ps3.data.analog.stick.ry;
  if (abs(ry) > config::STICK_DEAD_ZONE)
  {
    const int delta = -ry / config::RAMP_SCALE;
    const int next = constrain((int)rgb::brightness() + delta, 0, 255);
    if (next != (int)rgb::brightness())
    {
      rgb::setBrightness((uint8_t)next);
    }
  }

  // Left stick Y + held face button → tweak that preset's channels
  const int8_t ly = Ps3.data.analog.stick.ly;
  if (abs(ly) > config::STICK_DEAD_ZONE)
  {
    const int delta = -ly / config::RAMP_SCALE;
    if (Ps3.data.button.triangle) rgb::adjustPreset(rgb::GREEN, delta);
    if (Ps3.data.button.circle)   rgb::adjustPreset(rgb::RED, delta);
    if (Ps3.data.button.square)   rgb::adjustPreset(rgb::PINK, delta);
    if (Ps3.data.button.cross)    rgb::adjustPreset(rgb::BLUE, delta);
  }

  delay(20);
}

} // namespace controller

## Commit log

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2026-05-16 feat: stream PS3 controller events over serial
    Replace the boot blink sketch with a PS3Controller-based handler that
    binds the ESP's burned-in BT MAC, prints button/stick events to serial,
    and uses GPIO19 as a connection-status LED (solid on connect, blinking
    while waiting).
2026-05-16 feat(scripts): add pair-ps3 helper to write host MAC over USB
    PS3 controllers don't pair the normal way — they store a single host
    MAC internally and only connect to that one address. This script reads
    the controller's current paired MAC and (optionally) writes a new one
    via HID feature report 0xF5.
    Uses uv's PEP 723 inline deps to pull hidapi at runtime, so no extra
    install step is needed.
2026-05-16 feat: mirror PS3 face buttons to LEDs on GPIO 17/33/32/25
    Each face button drives its own LED on while held: triangle/circle/
    cross/square map to GPIO 17/33/32/25 respectively. Renames the old
    LED_PIN to STATUS_LED to make the connection-indicator role explicit,
    and clears all button LEDs on disconnect.
2026-05-16 feat: dim LEDs with left stick and latch buttons to toggle them
    Switch the four face-button LEDs to PWM (LEDC, 8-bit @ 5kHz) so brightness
    is adjustable, and change the button behaviour from hold-to-light to
    toggle-on-press. Left stick Y ramps a global brightness up/down while
    pushed; the dead zone keeps idle stick drift from drifting brightness.
2026-05-16 docs: add research notes covering hardware, software, and wiring plan
    Captures everything learned so far: ESP32 board specs, PS3 controller
    clone quirks, N20 motor analysis, motor driver shootout (TB6612FNG
    wins), pairing model, GPIO constraints, H-bridge control theory, power
    topology, and the 2-driver tank-drive wiring plan.
2026-05-16 docs: switch wiring plan to paired motors per side (1 driver, 6 GPIOs)
    Each side's two N20 motors are wired in parallel and treated as a
    single logical motor, so the four-motor tank drive only needs one
    TB6612FNG with one channel per side. Trades 1 driver + 6 GPIOs against
    ~2x stall current per channel (still within TB6612FNG headroom).
2026-05-16 docs: lock in 6V 400 RPM N20s with 20mm shaft
    Pin down the actual motors we bought (availability dictated 400 RPM
    instead of the ideal 600), record the voltage/shaft/RPM reasoning, and
    update the expected speed math at 3.7V with 33mm wheels.
2026-05-16 docs: identify ESP32 board as WeMos LOLIN32 Lite
    Replace the generic 38-pin description with the specific LOLIN32 Lite
    identification: built-in JST + TP4054 charging + the '+' pin that
    re-exposes raw battery voltage directly to the motor driver's VM rail.
2026-05-16 docs: add chassis section — PETG-translucent motor sandwich, invertible
    Captures the chassis design: two 3mm plates with motor half-pockets
    sandwiching the motor cavity, total height equal to the motor diameter
    (~18mm with wheels protruding equally top + bottom = invertible). PETG
    translucent is the chosen material; bonus affordance is that internal
    LEDs glow through the whole chassis. Includes print parameters,
    tolerance notes, side-access requirements, and a design checklist.
2026-05-16 refactor: extract pin and PWM constants to config.h
2026-05-16 refactor: extract status_led and leds modules from main.cpp
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2026-05-16 docs: add OpenSCAD chassis source and matplotlib top-down layout
    [chassis.scad]
2026-05-16 docs: add bill of materials with cost tiers and vendor table
2026-05-16 docs: rewrite README with schematics, chassis, BOM, and full setup guide
2026-05-16 feat(cad): enclosed chassis with side walls and wheels inside the perimeter
    [chassis.scad]
2026-05-16 docs: update research.md chassis section for enclosed shell design
2026-05-16 docs: update README chassis description for enclosed-shell design
2026-05-17 feat(cad): motors shaft-outward with wheels tucked just inside the side walls
    [chassis.scad]
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2026-05-17 feat: add buzzer module using LEDC for square-wave tone output
2026-05-17 feat: switch firmware to RGB preset + buzzer test program
    [controller.cpp]
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2026-05-17 fix: drop green channel from pink preset to keep it from washing to white
    [rgb.cpp]
2026-05-17 feat(cad): move driver to front, rotate ESP32 + battery 90 degrees for balanced mass
    [chassis.scad]
2026-05-17 feat(cad): move USB slot to the back wall centred behind the ESP32
    [chassis.scad]
2026-05-17 docs: rewrite README — Mermaid diagrams, rename BOM to Parts, drop assembly/software sections
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2026-05-17 feat(cad): narrow chassis from 130 to 110 mm by bringing motor track in to 35 mm
    [chassis.scad]
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2026-05-17 feat(cad): add GY-521 IMU pocket between rear motors and back wall
    [chassis.scad]
2026-05-17 docs: add IMU to overview, wiring table, parts list, and system diagram
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2026-05-17 docs: document the IMU auto-flip approach in the design notes
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2026-05-19 feat(schematics): switch to KiCad-based electronic schematic via kicad-cli
    [circuit.kicad_sch]
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2026-05-22 feat(cad): integrate TP4056 USB-C charging board and extend chassis to 150 mm
    [chassis.scad]
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2026-05-22 chore: drop KiCad schematic build artifacts
    [circuit.kicad_sch]
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2026-05-22 fix(cad): move IMU clear of the rear wheel cutout
    [chassis.scad]
2026-05-22 fix(cad): shift IMU outward to clear the rear motor body
    [chassis.scad]
2026-05-22 fix(cad): drop IMU lower to leave 3mm gap above the rear wheel
    [chassis.scad]
2026-05-31 docs(parts): swap TB6612FNG for DRV8833 dual motor driver
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2026-05-31 feat(cad): apply measured part dimensions (ESP 49x26, DRV8833 18.5x11, IMU 20x15.5)
    [chassis.scad]
2026-05-31 docs: switch motor driver from TB6612FNG to DRV8833 and lock in measured part dimensions
    [chassis.scad]
2026-05-31 feat(cad): apply measured N20 motor dimensions (12 wide x 10 high)
    [chassis.scad]
2026-05-31 feat: update motor length to 26mm and switch fasteners to M2.5
    [chassis.scad]
2026-05-31 docs: rename GY-521 to MPU-6050 to match the silkscreen on the board
    [chassis.scad]
2026-05-31 fix(cad): correct DRV8833 measured size to 16x18.5 mm
    [chassis.scad]
2026-05-31 feat(cad): switch to JS2622 wheels (28mm OD with rubber, 22mm wide) and shrink motor track
    [chassis.scad]
2026-05-31 feat(cad): widen chassis to 120mm, drop walls to 2.5mm, move MPU next to DRV, add side view
    [chassis.scad]
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2026-05-31 fix(cad): centre the DRV8833 + MPU pair symmetrically around y=0 in front of the motors
    [chassis.scad]
2026-05-31 fix(cad): rotate MPU 90 degrees and add 2mm gap between MPU and DRV stack
    [chassis.scad]
2026-05-31 fix(cad): drop side view, keep just the top-down layout
    [layout.py]
2026-05-31 docs: clarify the LOLIN32 + pad is next to the JST, not a side-header pin
2026-06-03 feat: lock in measured 603048 battery (48x30x6, 1000mAh) and fix stale wheel/driver refs
    [chassis.scad]
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2026-06-03 fix(cad): bump battery length to measured ~50mm (603048 incl. sealed lip)
    [chassis.scad]
2026-06-03 feat(cad): measured wheels (23x25mm), recompute speed, update wheel cutouts
    [chassis.scad]
2026-06-03 docs(cad): document wheel-on-shaft flush geometry assumption
    [chassis.scad]
2026-06-03 feat(cad): optimal part layout — centred battery, flanking DRV/MPU, ESP front, TP4056 back
    [chassis.scad]
2026-06-03 fix(cad): swap wheel dims to measured ⌀25 x 23mm wide
    [chassis.scad]
2026-06-03 feat(cad): widen track to 35mm for tyre-ESP clearance, 2mm tyre-wall gap, plate 150x116
    [chassis.scad]
2026-06-03 feat(cad): nudge motor track to 32mm (tyres a touch closer), plate unchanged
    [chassis.scad]
2026-06-04 feat(cad): wheels-in-corners layout — 110mm wheelbase, central board cluster, edge mounts
    [chassis.scad]
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2026-06-04 feat(cad): screws back at corners, DRV+MPU moved to the sides, wheelbase 95
    [chassis.scad]
2026-06-04 fix(cad): stack battery+ESP flat in centre (no overlaps), shrink length to 144
    [chassis.scad]
2026-06-04 feat(cad): narrow to 113mm — TP4056 behind rear motors lets track drop to 32mm
    [chassis.scad]
2026-06-04 Revert "feat(cad): narrow to 113mm — TP4056 behind rear motors lets track drop to 32mm"
    This reverts commit 45b81c27171deabb390aa771f18b2ee58f138e3a.
    [chassis.scad]
2026-06-04 feat(cad): tighten board-to-motor gap (wheelbase 84) and shrink length to 134
    [chassis.scad]
2026-06-04 feat(cad): widen to 127mm for 1mm tyre-wall gap (track 48), trim length to 130
    [chassis.scad]
2026-06-04 feat(cad): square 130x130 footprint
    [chassis.scad]
2026-06-04 feat(cad): wheelbase 80 — wheels a few mm clear of the corner screws
    [chassis.scad]
